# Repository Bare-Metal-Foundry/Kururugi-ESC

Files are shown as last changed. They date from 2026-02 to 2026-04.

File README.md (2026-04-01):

# ⚡ Kururugi - Electronic Speed Controller (ESC) ⚡ 

> 4/6S-ready • 64–96 kHz PWM • FOC/Six-Steps • Full bare-metal control

<p align="center">
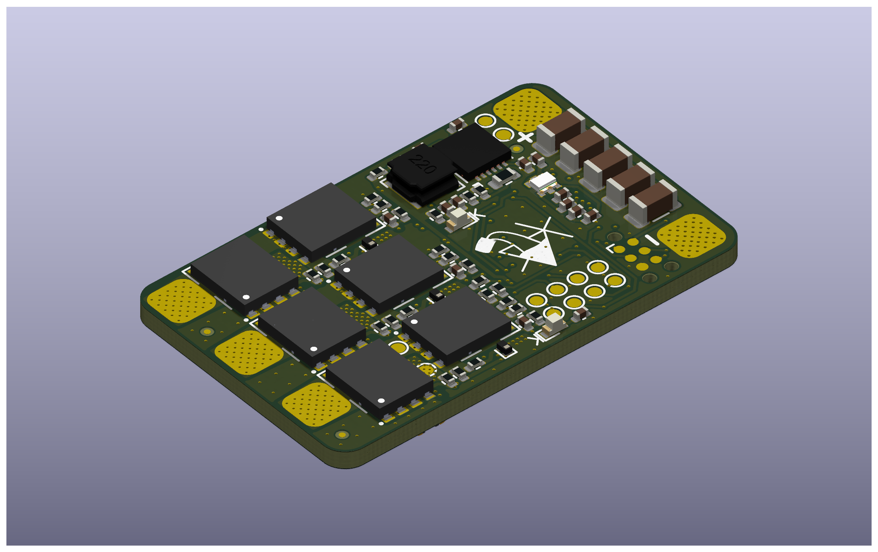
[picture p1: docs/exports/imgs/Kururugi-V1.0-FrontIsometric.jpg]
  
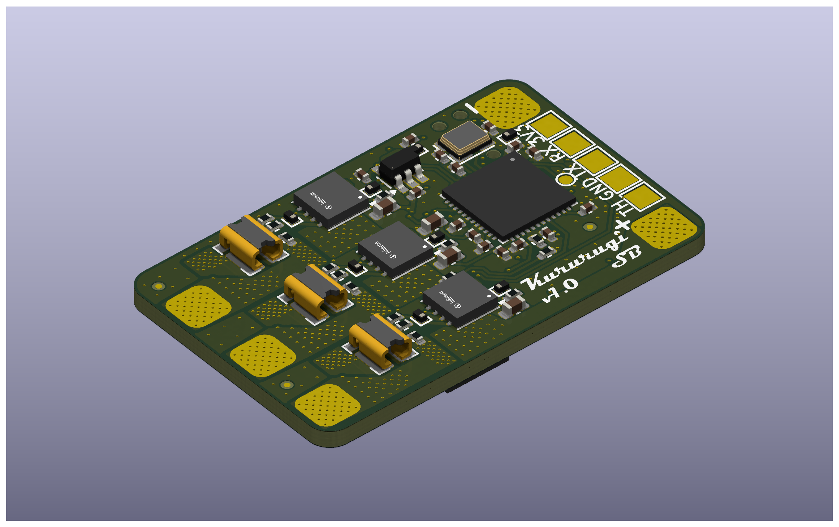
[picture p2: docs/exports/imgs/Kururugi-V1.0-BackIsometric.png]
  
  <br>
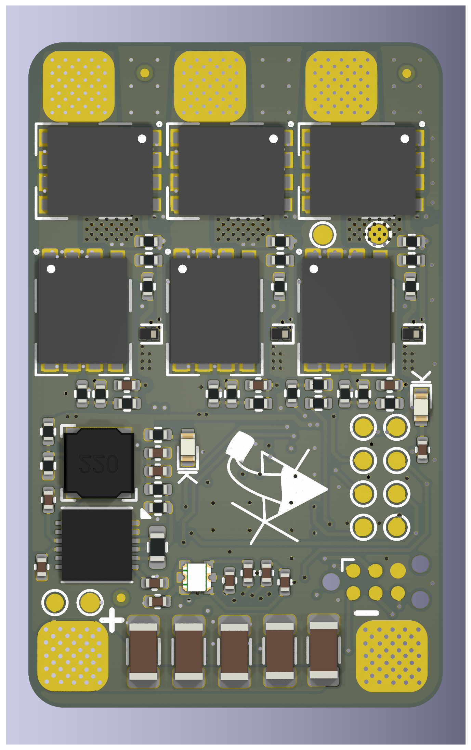
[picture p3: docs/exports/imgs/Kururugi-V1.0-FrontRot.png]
  
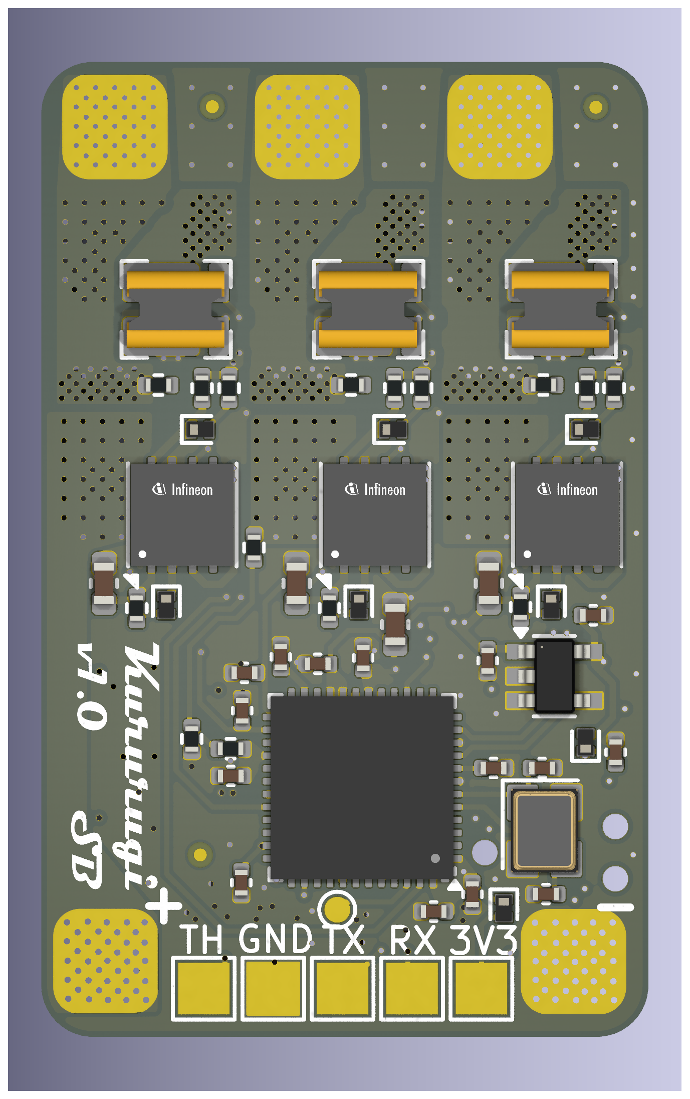
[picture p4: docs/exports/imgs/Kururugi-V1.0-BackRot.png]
  
</p>

## ⚙️ Project overview

Kururugi is a high-performance ESC designed for FPV drones, built as a platform for low-level motor control, power electronics optimization, and embedded system experimentation.

It is developed within the **Bare Metal Foundry** initiative for autonomous racing drones, alongside the Shirley Flight Controller - forming a complete, fully controlled hardware and software stack.

This README provides an overview of the project and repository structure. Detailed hardware and ESC design information is available in: 📊 [Technical Specifications](docs/hw-kururugi-specs.md)

## ❓ Why Kururugi?

Most ESCs are closed, optimized for mass production - not understanding.

Kururugi is designed to:
- Push switching frequency limits (64 kHz in v1.0, targeting 96 kHz+ in future revisions)
- Provide full transparency and control over the motor stack (no black boxes)
- Enable high-speed bare-metal control
- Serve as a platform for developing and validating Six-Step and Field-Oriented Control (FOC)
- Bring together makers and engineers to explore, experiment, and push boundaries

👉 This is an research platform, not just an ESC.

## 🚢 Navigate the repo

> ⚠️ Documentation is still a work in progress. Detailed design notes and analysis will be added progressively.

### 📂 Not to miss documents:
- 🧩 **Hardware (KiCad)**: [KiCad project](hardware/Kururugi-ESC-KiCad/)
- 📊 **Design & Sizing**: [Design notes](docs\Kururugi-ESC-sizing.xlsx)
- 📊 **Technicals specifications**: [Documentation](docs/hw-kururugi-specs.md)
- 📤 **Exports**: [Schematics, PCB renders, STEP files](docs/exports)
- 📚 **Resources**: [Datasheets & Engineering Notes](resources/datasheets)

## 💻 Run it yourself

### 📟 H/W - PCB desgin
To get started, simply clone the repository and proceed to open the project on Kicad 9.0.4. All libraries are self containts so it is no more difficult than this.
```bash
git clone https://github.com/StepaneBinon/Kururugi-ESC-Dev-Board.git
```

### 📟 H/W — PCB Manufacturing

PCB fabrication and assembly are handled through JLCPCB. The minimum order quantity is 5 boards for PCB fabrication and 2 boards for assembly. With the selected options, the total cost is 255.13 € (295.01 USD).

Production files are available in [Production files](hardware/Kururugi-ESC-KiCad/Production/).  
When placing the order, use the parameters shown in [JLCPCB Options](hardware/Kururugi-ESC-KiCad/Production/JLCPCB%20-%20Options%20to%20use.png).

> ⚠️ Ensure BOM/CPL match and components are available before ordering.
> ⚠️ This design is provided as-is; no guarantee is made regarding functionality or performance.

### 🔢 S/W - Kururugi-6Step [WORK IN PROGRESS]

### 🔢 S/W - Kururugi-FOC [WORK IN PROGRESS]

## 🚀 Roadmap

### ⚡ Hardware
1. 🧪 **V1.0 Production & Bring-up** *(Apr 2026)*: First batch with JLCPCB, full electrical validation
2. 📖 **Design Documentation** *(May 2026)*: Complete breakdown of sizing, losses, and trade-offs
3. 🔌 **Multi-ESC Test Bench** *(Jun–Jul 2026)*: Dedicated rig for synchronized testing and stress scenarios
4. 🏁 **Drone Validation (V1)** *(Jul–Aug 2026)*: High-load FPV testing on 6-inch platform
5. 🤖 **Robotics Validation (V1)** *(Jul–Aug 2026)*: Differential drive platform for control robustness
6. 📝 **Technical Paper (V1 Results)** *(Sep 2026)*: Performance, efficiency, and design insights
7. ⚡ **V2 Hardware** *(2027)*: Sensor simplification, FOC/6-step optimization, possible 4-in-1

### 🧠 Software
1. 🏗 **Bare-Metal C++ Architecture** *(Apr–May 2026)*: Deterministic design, coding standards, HAL strategy (rewrite vs minimal use)
2. ⚙️ **6-Step Control (Baseline)** *(May–Jun 2026)*: Reliable startup and fallback mode
3. 🎯 **FOC Implementation** *(Jun–Aug 2026)*: High-efficiency, high-performance control
4. 📝 **Technical Paper (Control & Results)** *(Sep 2026)*: Control strategy, tuning, and comparison

## 🤝 How to Contribute

> Alone we go faster, together we go further.

Contributions are more than welcome, at all levels:

- 🐛 **Report issues**: bugs, design flaws, or unclear documentation
- 💡 **Suggest improvements**: hardware, firmware, or architecture ideas
- 🧪 **Test & validate**: share results, measurements, or flight data
- 📖 **Improve documentation**: clarify concepts, add explanations

### 📬 Get involved

- Open an issue for discussion  
- Submit a pull request  
- Share your insights or experiments 
- Join the **Bare Metal Foundry** discord here: https://discord.gg/e7CF2AZCN 

👉 If you're working on ESCs, power electronics, or embedded control, your feedback is highly valuable.

## 🪪 Licensing

### Hardware
Hardware design (schematics, PCB, KiCad) is licensed under CERN-OHL-S v2. This project is released as open hardware.
Any modifications or derived designs must be shared under the same license.

For commercial use, collaboration, or licensing inquiries, please reach out.

## 👤 Author

This project was originally created and is actively maintained by [Stepane Binon](https://github.com/StepaneBinon).

Parts of the documentation are generated with the assistance of AI tools to streamline development.

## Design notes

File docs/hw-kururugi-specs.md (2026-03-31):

# ⚡ Kururugi ESC - Technical Specifications

> Detailed hardware architecture and performance targets

## 🧭 Overview

Kururugi is a compact, high-performance ESC designed for drones and differential-drive robotics. The design focuses on high switching frequency operation, low parasitics, and precise sensing. This version is sensorless, which limits low-speed performance. Detailed sizing is available in:
```
docs/Kururugi-ESC-sizing.xlsx
```

The design is inspired by the B-G431B-ESC1.

## 📟 Board Presentation

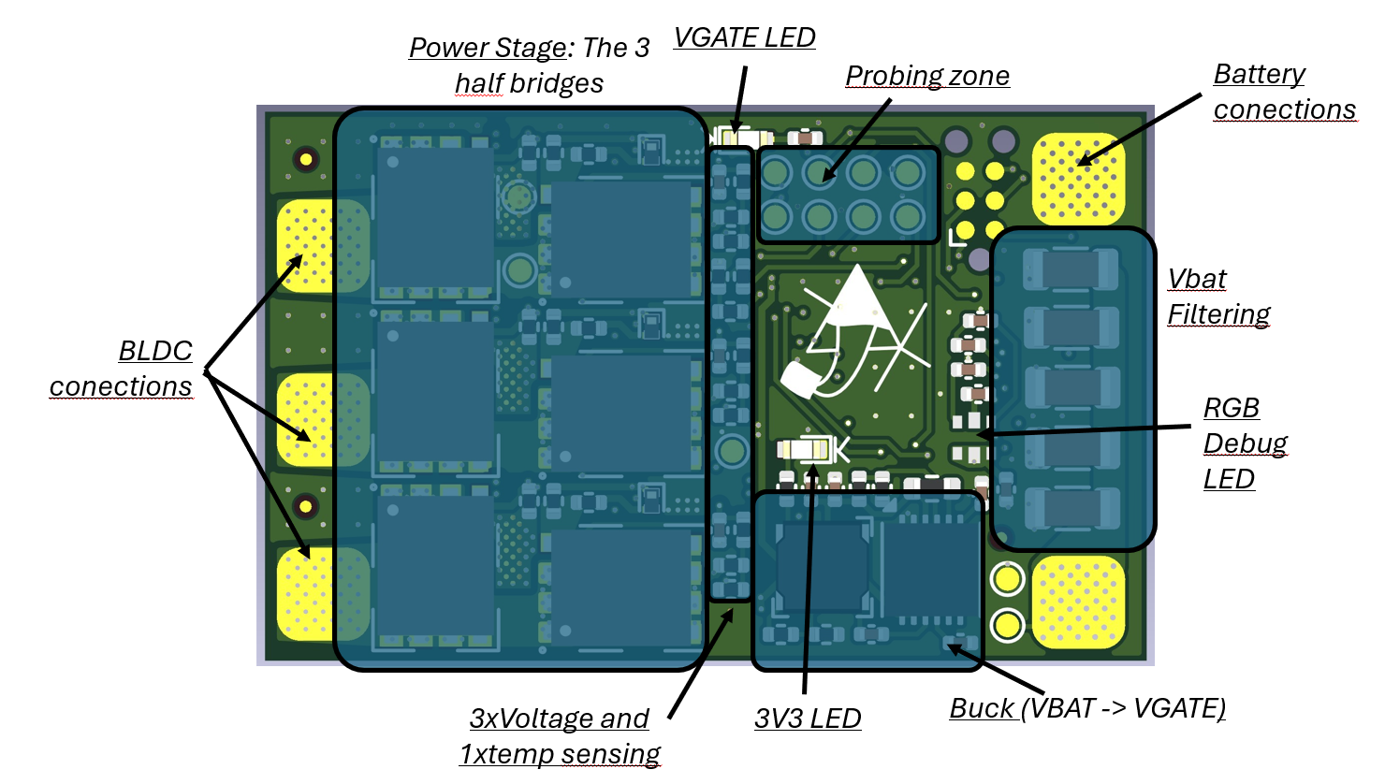
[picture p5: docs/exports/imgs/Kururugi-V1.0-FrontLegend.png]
Front

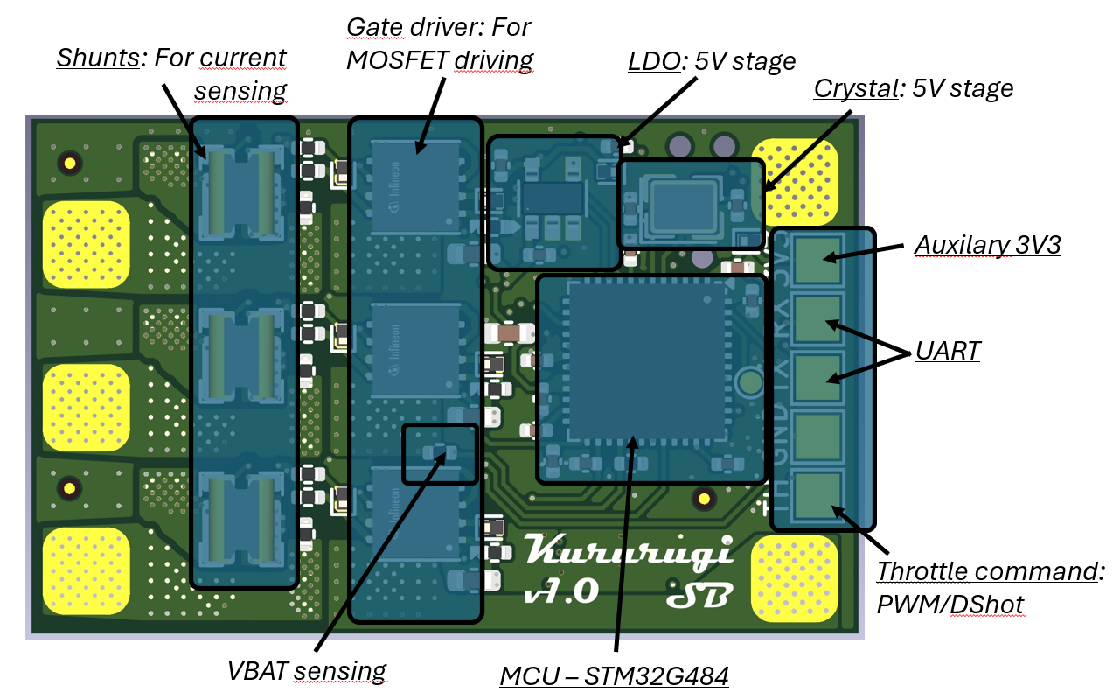
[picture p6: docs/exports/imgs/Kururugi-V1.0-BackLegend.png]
Back


## 🧱 PCB Stackup (6 Layers)

The stackup is optimized for current density, thermal performance, and EMI control.

<table>
<tr>
<td>

**Layer 1 - Power (MOSFET, BUCK)**  
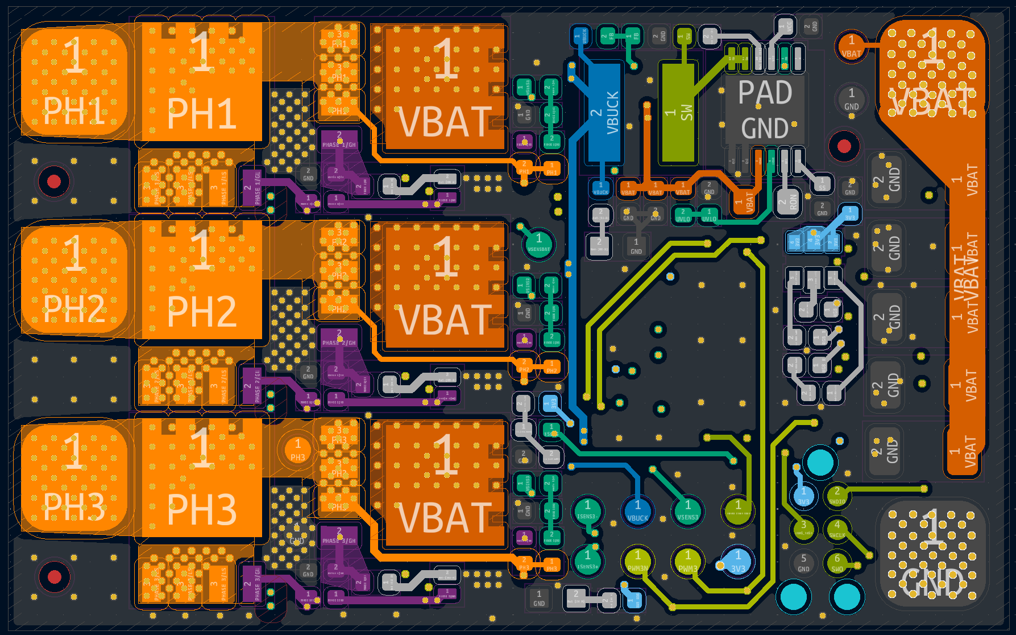
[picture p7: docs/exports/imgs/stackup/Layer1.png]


</td>
<td>

**Layer 2 - GND plane**  
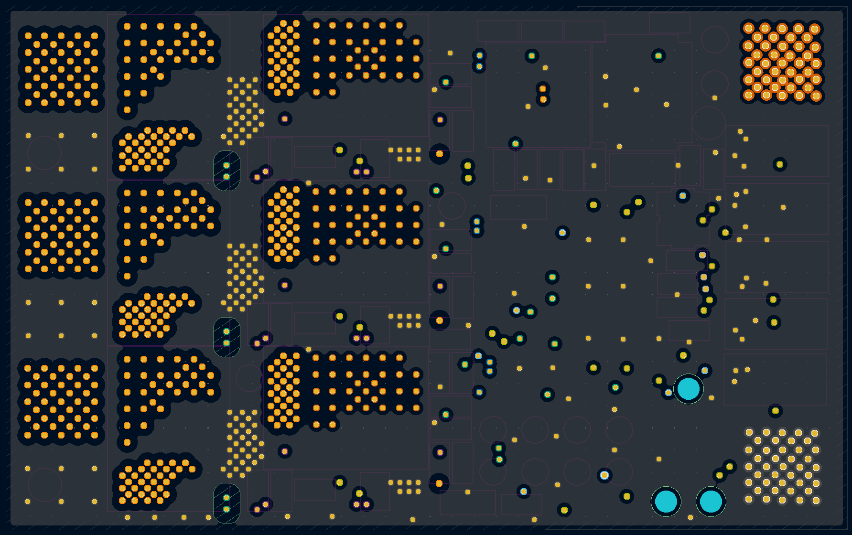
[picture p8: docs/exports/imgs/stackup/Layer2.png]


</td>
</tr>

<tr>
<td>

**Layer 3 - VBAT plane**  
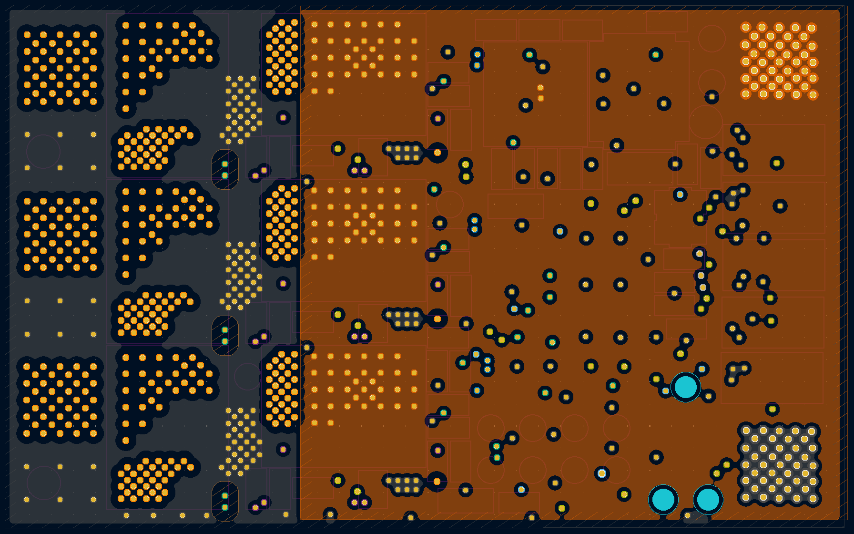
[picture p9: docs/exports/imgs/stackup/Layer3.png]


</td>
<td>

**Layer 4 - Signal routing**  
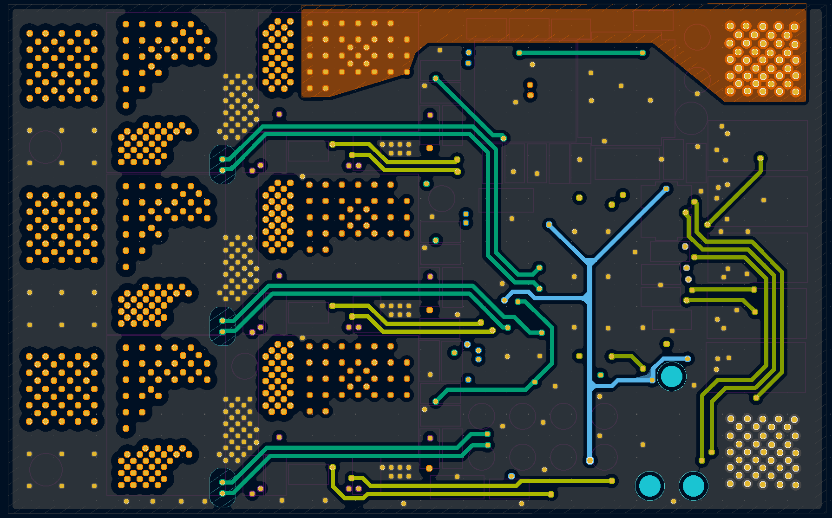
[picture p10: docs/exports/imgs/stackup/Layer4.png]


</td>
</tr>

<tr>
<td>

**Layer 5 - Clean GND reference**  
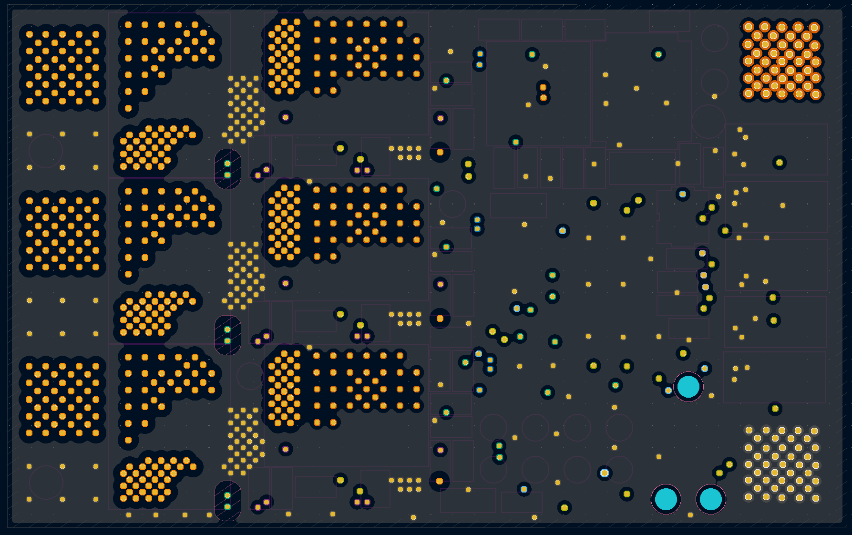
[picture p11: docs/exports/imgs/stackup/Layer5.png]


</td>
<td>

**Layer 6 - Control (MCU, shunts, LDO)**  
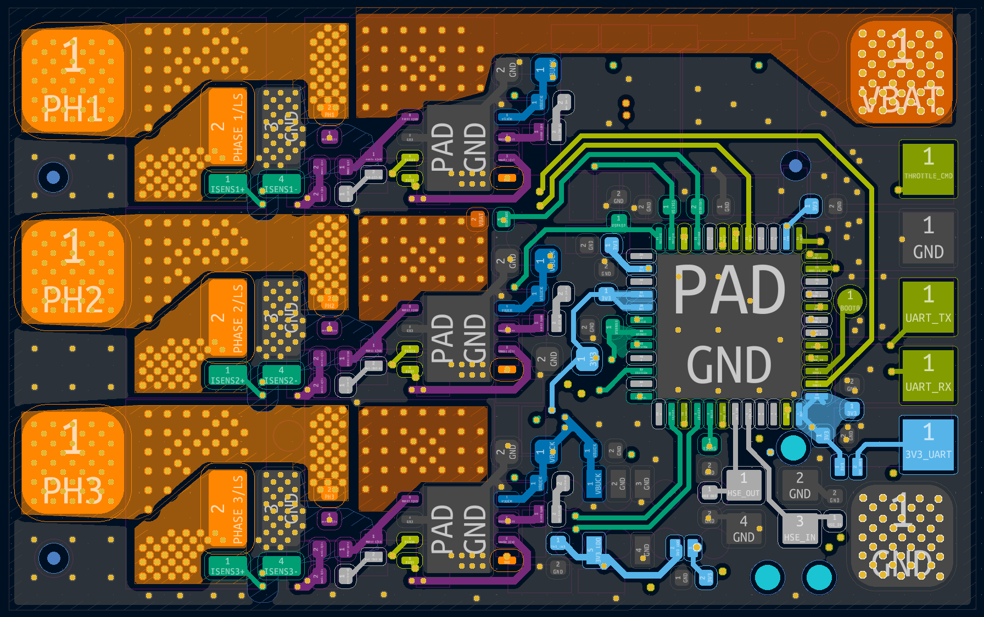
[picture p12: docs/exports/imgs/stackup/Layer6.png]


</td>
</tr>
</table>
Outer layers use 2 oz copper, and vias are filled and capped for reliable via-in-pad and thermal conduction.

## ⚙️ Subsystemps

### 1. 🧠 MCU & Sensing [[details](./hw-mcu-and-sensing.md)]

The system is built around the stm32g474 with advanced timers, ADCs, and internal op-amps.

Phase current is measured using 0.5 mΩ shunts with Kelvin routing and internal amplification. VBAT and optional phase voltages are measured through resistor dividers.

ADC sampling is optimized for speed (~2.5 cycles), with careful impedance control. A third current channel is optional due to ADC limitations.

### 2. 🔋 Power System [[details](.\hw-power-system.md)]

Three power rails are present on the board. First is VBAT, provided directly by the battery input. Then, this rails is lowered to 11.5V for the MOSFET gate driving. Finally a third rail lower the VBUCK rail to 3V3 to power the MCU and LEDs.

An extenal 3V3 pad is exposed to work with the MCU using an external power supply to work directly from an UART converter easily.

More information on the power stage can be found here: 

### 3. ⚡ Power Stage [WORK IN PROGRESS]

The design uses a three-phase half-bridge directly supplied from VBAT. Layout minimizes switching loop area and parasitic inductance while ensuring good thermal spreading.

### 4. 🚪 Gate Driving [WORK IN PROGRESS]

A high-current gate driver (~3 A / ~5 A) enables fast switching. Asymmetric gate resistors allow tuning of switching behavior and EMI.

Bootstrap capacitor sizing is critical and defined in the sizing spreadsheet.

### 5. 🌡️ Monitoring [WORK IN PROGRESS]

An NTC thermistor provides board temperature monitoring.

### 6. 📡 Communication [WORK IN PROGRESS]

A UART interface enables telemetry and future real-time monitoring tools. USB was not retained due to layout constraints.

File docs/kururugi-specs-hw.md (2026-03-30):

# ⚡ Kururugi ESC - Technical Specifications

> Detailed hardware architecture and performance targets

## 🧭 Overview

Kururugi is a compact, high-performance ESC designed for drones and differential-drive robotics. The design focuses on high switching frequency operation, low parasitics, and precise sensing.

This version is sensorless, which limits low-speed performance. Detailed sizing is available in:
```
docs/Kururugi-ESC-sizing.xlsx
```

The design is inspired by the B-G431B-ESC1.

## 📟 Board Presentation

Front
Back

## 🧱 PCB Stackup (6 Layers)

The stackup is optimized for current density, thermal performance, and EMI control.

<table>
<tr>
<td>

**Layer 1 - Power (MOSFET, BUCK)**  


</td>
<td>

**Layer 2 - GND plane**  


</td>
</tr>

<tr>
<td>

**Layer 3 - VBAT plane**  


</td>
<td>

**Layer 4 - Signal routing**  


</td>
</tr>

<tr>
<td>

**Layer 5 - Clean GND reference**  


</td>
<td>

**Layer 6 - Control (MCU, shunts, LDO)**  


</td>
</tr>
</table>
Outer layers use 2 oz copper, and vias are filled and capped for reliable via-in-pad and thermal conduction.

## ⚙️ Subsystemps

### 🔋 Power System

The ESC operates from 4S–6S LiPo input. VBAT feeds the power stage directly, while a BUCK converter generates ~11.5 V for the gate driver and an LDO provides 3.3 V for logic.

An optional external 3.3 V input allows independent MCU powering. External capacitors are recommended to reduce ringing from wiring inductance.

### ⚡ Power Stage

The design uses a three-phase half-bridge directly supplied from VBAT. Layout minimizes switching loop area and parasitic inductance while ensuring good thermal spreading.

### 🚪 Gate Driving

A high-current gate driver (~3 A / ~5 A) enables fast switching. Asymmetric gate resistors allow tuning of switching behavior and EMI.

Bootstrap capacitor sizing is critical and defined in the sizing spreadsheet.

### 🧠 MCU & Sensing

The system is built around the STM32G484 with advanced timers, ADCs, and internal op-amps.

Phase current is measured using 0.5 mΩ shunts with Kelvin routing and internal amplification. VBAT and optional phase voltages are measured through resistor dividers.

ADC sampling is optimized for speed (~2.5 cycles), with careful impedance control. A third current channel is optional due to ADC limitations.

### 🌡️ Monitoring

An NTC thermistor provides board temperature monitoring.

### 📡 Communication

A UART interface enables telemetry and future real-time monitoring tools. USB was not retained due to layout constraints.

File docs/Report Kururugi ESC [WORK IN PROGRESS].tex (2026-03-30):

\documentclass[11pt,a4paper]{article}

% =========================================================
% Packages
% =========================================================
\usepackage[a4paper,margin=25mm]{geometry}
\usepackage[T1]{fontenc}
\usepackage[utf8]{inputenc}
\usepackage{lmodern}
\usepackage{microtype}

\usepackage{amsmath, amssymb}
\usepackage{siunitx}
\usepackage{physics}
\usepackage{graphicx}
\usepackage{float}
\usepackage{subcaption}
\usepackage{booktabs}
\usepackage{tabularx}
\usepackage{array}
\usepackage{longtable}
\usepackage{multirow}
\usepackage{enumitem}
\usepackage{xcolor}
\usepackage{hyperref}
\usepackage[nameinlink]{cleveref}
\usepackage{caption}
\usepackage{listings}
\usepackage{tikz}
\usepackage{multicol}
\usepackage{siunitx}

% =========================================================
% Hyperref setup
% =========================================================
\hypersetup{
    colorlinks=true,
    linkcolor=blue,
    citecolor=blue,
    urlcolor=blue,
    pdftitle={ESC Design Report},
    pdfauthor={Your Name},
    pdfsubject={Electronic Speed Controller Design},
    pdfkeywords={ESC, power electronics, PCB, motor control, STM32}
}

% =========================================================
% siunitx setup
% =========================================================
\sisetup{
    per-mode=symbol,
    separate-uncertainty=true,
    range-phrase=--,
    range-units=single
}

% =========================================================
% Custom commands
% =========================================================
\newcommand{\projectname}{Kururugi ESC}
\newcommand{\todo}[1]{\textcolor{red}{[TODO: #1]}}
\newcommand{\figref}[1]{Fig.~\ref{#1}}
\newcommand{\tabref}[1]{Table~\ref{#1}}
\newcommand{\secref}[1]{Section~\ref{#1}}

% =========================================================
% Title
% =========================================================
\title{\textbf{\projectname}\\Design and Sizing Report}
\author{Your Name}
\date{\today}

% =========================================================
% Document
% =========================================================
\begin{document}

\maketitle
\tableofcontents
\newpage

% =========================================================
\begin{abstract}
This document presents the design, sizing, schematic capture, and PCB implementation of the \projectname.
The objective is to justify the main design choices, validate the electrical calculations, and document the final hardware implementation. To speed up the process, this document was co-written with an AI assistant.
\end{abstract}

% =========================================================
\section{Introduction}
\label{sec:introduction}

\subsection{Project context}

Electronic Speed Controllers (ESCs) are critical components in electric propulsion systems, converting battery power into controlled three-phase signals to drive brushless DC (BLDC) motors. In high-performance applications such as FPV drones, ESCs must operate under demanding conditions including high current peaks, fast switching frequencies, limited PCB area, and strong electromagnetic constraints.

This project focuses on the design of a compact and high-performance ESC tailored for aggressive drone operation. The target system requires reliable operation over a wide input voltage range (4S to 6S LiPo), high efficiency at elevated switching frequencies, and precise current sensing for advanced motor control strategies.

Beyond its functional objective, this ESC was also developed as a foundational learning project to gain hands-on experience in PCB design and low-level embedded development. It is conducted alongside the \href{https://github.com/Gui-arain/Shirley-FC-Dev-Board/tree/main/resources}{Shirley-FC development board} by \textit{Guilhem Andrieu}, forming a coherent hardware and firmware development platform.

These projects aim to serve as the technological basis for the development of fast, fully autonomous drones, and constitute the initial building blocks of the \textit{Bare Metal Foundry}, an initiative focused on mastering embedded systems from hardware to high-level software.

\subsection{Objectives}

The objective of this project is to design a compact ESC for a 6-inch FPV drone, capable of reliable operation under high electrical and dynamic stress.

The ESC must operate from 13--25.2~V, with tolerance to voltage spikes up to 45~V (battery) and 35~V (phase). It shall sustain continuous phase currents of 12.5--15~A, with peaks up to 20--25~A and transient spikes up to 50--60~A. 
High-frequency operation is targeted, up to 64~kHz (V1.0) and 96~kHz (V2), with duty cycles up to 90--95\%.

Thermally, the design must ensure safe operation through proper loss distribution, efficient PCB heat spreading, and temperature monitoring using a thermistor. Mechanically, the ESC must fit a compact layout with minimized power loops and compatibility with standard drone integration.

Functionally, it must provide accurate sensing, robust transient behavior, and support low-level firmware for high-performance motor control.

% =========================================================
\section{System Overview}
\label{sec:overview}

\subsection{Functional description}

The ESC converts DC battery power into controlled three-phase signals to drive a BLDC motor. It regulates motor speed and torque through high-frequency PWM, while monitoring current, voltage, and temperature to ensure safe and efficient operation.

The system integrates power conversion, control, sensing, and protection functions within a compact PCB suitable for FPV drone applications.

\subsection{Top-level architecture}

The ESC is organized around the following main blocks:

\noindent
\begin{minipage}[t]{0.48\textwidth}
\begin{itemize}[noitemsep, topsep=0pt]
    \item STM32G4 MCU: control, PWM, acquisition
    \item Gate driver: MOSFET control
    \item Three-phase bridge: power stage
\end{itemize}
\end{minipage}
\hfill
\begin{minipage}[t]{0.48\textwidth}
\begin{itemize}[noitemsep, topsep=0pt]
    \item Sensing: current, voltage, temperature
    \item Power supplies: regulated rails
    \item Interfaces: UART, JTAG (debug/config)
\end{itemize}
\end{minipage}

\subsection{Main design specifications}

\begin{table}[H]
    \centering
    \caption{Main design specifications}
    \begin{tabularx}{\textwidth}{>{\bfseries}l X}
        \toprule
        Parameter & Value / Description \\
        \midrule
        Input voltage & 13--25.2~V nominal (4S--6S LiPo), up to 45~V transient \\
        Continuous current & 12.5--15~A per phase \\
        Peak current & 20--25~A short duration, up to 50--60~A transient \\
        PWM frequency & Up to 64~kHz (V1.0), 96~kHz (V2) \\
        Control MCU & STM32G4 series (advanced timers, ADC, op-amps) \\
        Gate driver & Infineon 2EDL8024 \\
        MOSFETs & Low R\textsubscript{DS(on)} N-channel power MOSFETs (e.g. 60~V class) \\
        PCB dimensions & Compact ESC form factor for 6-inch drone (approx. 30~mm class) \\
        \bottomrule
    \end{tabularx}
    \label{tab:specs}
\end{table}

% =========================================================
\subsection{Design inputs and assumptions}

The first hardware revision targets a 4S--6S LiPo FPV ESC. The main design assumptions are:
\begin{itemize}[noitemsep, topsep=0pt]
    \item Input voltage from 13--25.2~V, with transients up to 45~V (battery) and 35~V (phase),
    \item Gate-driver supply around 10~V,
    \item PWM frequency up to 64~kHz (V1.0), with higher frequencies as future targets,
    \item Maximum duty cycle up to 95\%,
    \item Phase current in the 12.5--15~A range, with higher transient peaks,
    \item Conservative derating for temperature and MLCC DC bias.
\end{itemize}

A 10~V rail is generated from VBAT via a buck converter and post-regulated to 3.3~V for logic.

% =========================================================
\section{Electrical sizing}

Please refer to the sizing Excel.

% =========================================================

% =========================================================
\section{Schematic Design}
\label{sec:schematic}

\subsection{Schematic organization}

The schematic is structured into functional blocks reflecting the system architecture: power stage, gate driver, sensing, power supply, and control. This modular approach improves readability, reuse, and validation of each subsystem.

\subsection{Gate driver and power stage}

The power stage consists of a three-phase MOSFET bridge driven by the Infineon 2EDL8024 gate driver. Each half-bridge integrates bootstrap circuitry and asymmetric gate resistors to control switching speed and mitigate EMI. Particular attention is given to minimizing parasitic inductance in the switching loops and ensuring reliable high-duty-cycle operation.

\subsection{Sensing circuits}

Current sensing is implemented using low-value shunt resistors with analog amplification before ADC acquisition. Voltage sensing relies on resistive dividers with local RC filtering to ensure accurate sampling under fast switching conditions. Temperature monitoring is achieved using an NTC thermistor placed near a power MOSFET, enabling thermal supervision and derating.

\subsection{Power supply section}

The power supply is divided into two stages: a buck converter generating a 11.5~V intermediate rail from VBAT, followed by an LDO providing a clean 3.3~V rail for the MCU and analog circuits. Decoupling is applied locally at each critical node to ensure stability and reduce noise coupling. The 11.5V guarantee that, even with voltage drop from the overall circuit, the gate are driven at 10V, ensure rapid switching and thus minimizing switching losses.

\subsection{Microcontroller section}

The design uses an STM32G4 microcontroller, leveraging advanced timers for PWM generation and ADCs for synchronized measurements. Internal op-amps and comparators are used where appropriate to reduce external component count. Standard interfaces such as UART and JTAG are included for communication and debugging.

\subsection{Protection and robustness features}

The schematic integrates protection mechanisms including input voltage filtering, undervoltage lockout through the power stage, and careful layout of sensitive analog nodes. RC filtering and proper decoupling are used to mitigate switching noise. The design also considers robustness against transient events such as arming/disarming and load steps.

\subsection{Design review summary}

The schematic reflects a trade-off between performance, compactness, and robustness. Low $R_{\mathrm{DS(on)}}$ MOSFETs reduce conduction losses but increase switching constraints, requiring careful gate-drive design. Analog sensing accuracy is balanced against noise sensitivity, and the power architecture prioritizes clean supply rails over maximum efficiency. Overall, the design is consistent with the targeted operating conditions and provides a solid foundation for PCB implementation.

% =========================================================
\section{PCB Design}
\label{sec:pcb}

\subsection{Board constraints and objectives}
\todo{Size, layer count, current capability, manufacturability.}

\subsection{Stack-up definition}
\todo{Describe layers and their functions.}

\subsection{Component placement strategy}
\todo{Critical loops, thermal distribution, accessibility.}

\subsection{Power routing}
\todo{Phase paths, battery paths, copper width, polygon use, via stitching.}

\subsection{Signal routing}
\todo{Gate signals, ADC traces, sensitive nets, debug interfaces.}

\subsection{Grounding strategy}
\todo{Power ground vs quiet ground, return paths, stitching.}

\subsection{Thermal design features}
\todo{Copper areas, thermal vias, heat spreading.}

\subsection{Manufacturing and assembly considerations}
\todo{Courtyard, clearances, fiducials, test pads, DFM choices.}

\subsection{PCB review summary}
\todo{Main layout achievements and remaining limitations.}

% =========================================================
\section{Conclusion}
\label{sec:conclusion}

\subsection{Summary of the design}
\todo{Summarize the final ESC design and key results.}

\subsection{Main challenges and tradeoffs}
\todo{Discuss compromises made in sizing, schematic, and PCB.}

\subsection{Future improvements}
\todo{Possible hardware and firmware improvements.}

% =========================================================
\appendix

\section{Component List}
\label{app:bom}
\todo{Optional: add main BOM table.}

\section{Calculation Notes}
\label{app:calc}
\todo{Optional: add extra derivations not kept in main text.}

\section{Figures and Schematics}
\label{app:figures}
\todo{Optional: full-page schematic or PCB images.}

% =========================================================
\bibliographystyle{ieeetr}
% \bibliography{references}

\end{document}

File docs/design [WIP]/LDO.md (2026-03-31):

# LDO

The LDO is used to power the stm32g474. It will be powered by the 10V BUCK, hence no additionnal protection from battery spikes is required. However, the LDO input will have to handle the buck ripple and transient caused by the gate driver, that we estimed to be between 10kHz-100kHz. Moreother, the higher the Power Supply Rejection Ratio (PSRR), better the filtering of the noise. Hence, I chosed to go with the Texas Instrument TPS7B92, which, in addition to have a good PSRR, is well documented. It is rated for 300mA@3.3V, which should be enough for the MCU and some leds. However, its dropout voltage is quite hight, 1V@100mA to 3V@300mA, dissipating (10-3.3)*0.3=2W in heat. With this choice I sacrified heat for stability, which I don't think is a great choice for a digital supply. However, because my ADC sampling will be done in the MCU, this ensure, at least, a good AVcc if well used.

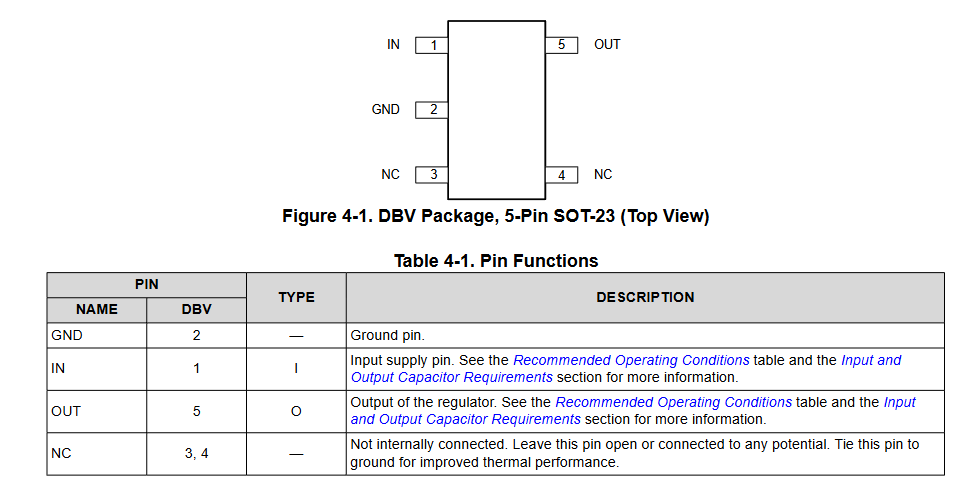
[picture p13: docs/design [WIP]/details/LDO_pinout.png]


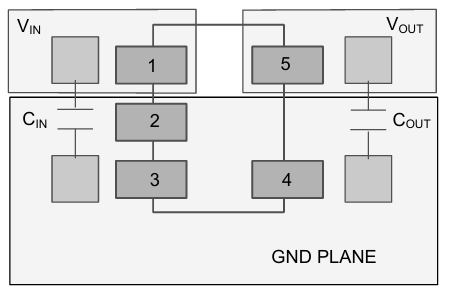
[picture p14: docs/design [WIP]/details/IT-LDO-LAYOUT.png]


## Technical Brief: Components selection.

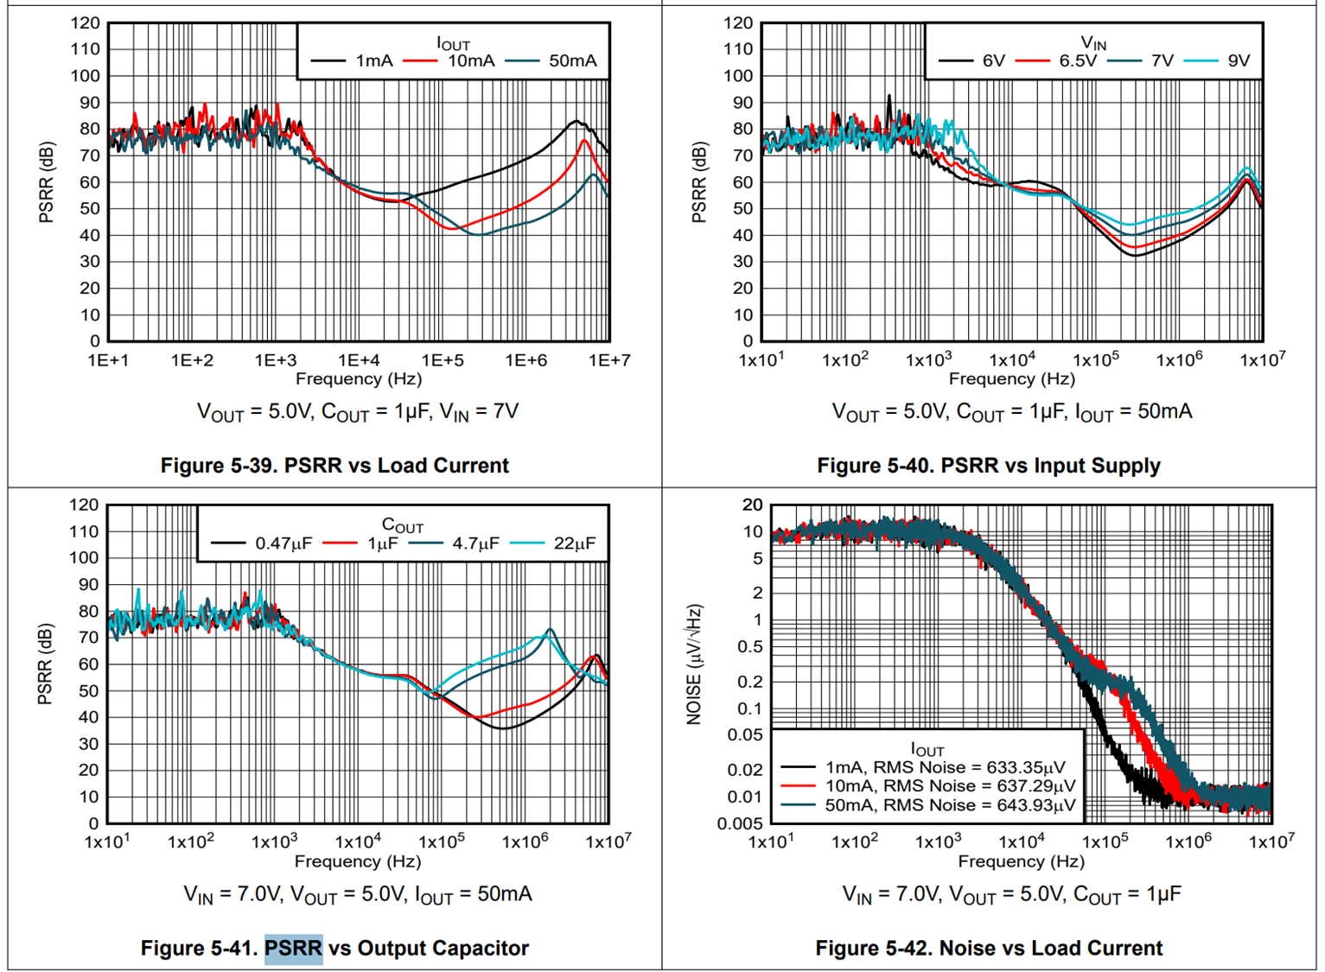
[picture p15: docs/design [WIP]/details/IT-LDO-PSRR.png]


These graphs, extracted from the database, illustrate the impact of different parameters on the PSRR. We will use a COUT=4.7µF as it balance size and performance. Finally we will rely on a CIN=1uF. The manufacturer advise to have at least 0.1µF.

The datasheet recommend to use a TVS diode in case we expect negative currents to flow in the device. However, as 10V>>3.3V, we do not expect any negative current. AS such, we wont add a TVS diode.

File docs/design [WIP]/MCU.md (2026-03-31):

# MCU: stm32g474CEU6

For the Microcontroller Unit, the stm32g474 will be used. It was chosen to use an STM MCU because we wanted to learn how to use them. We will select the smallest package as this should provide enough pins. We have two choices:

1. stm32g474CE**T**6: which comes in a LQFP48 (7x7mm) package
2. stm32g474CE**U**6: which comes in a UFQFPN48 (7x7mm) package and provide more GPIO pins, an UART port and 1 additionnal ADC channel compare to 1. It is also almost two times cheaper per unit on JLCPCB.

Thus, we will use a stm32g474CEU6 even if the soldering will be more challenging. Not that the stm32g474CEU6 does not have a dedicated VSSA pin, contrary to the STM32G474CET6, so we will need to be very careful about the layout so PWM gate signals returns and other fast varying signals returns do not cross ADC return paths.

## What is the STM32G4 familly ?

The G4 familly was specifically designed with motor control in mind an is a new adition to the STM32 catalog. The F4 is an other option we looked at, it is more general purpose. A key difference is that the G4 as stronger analogs (faster ADCs (4Msps vs 2Msps), more flexible triggering, often HRTIM, comparators, op-amps). F4 is less oriented toward power electronics.

To ensure we had some headroom for the development board we are going to use the STM32G474, one of the high tier of the familly. An other feature we looked for was the triple ADC, to reduce reading time, and the presence of an HRTIM, which are provided by the 484. An other nice to have for us is the precense of a:

- CORDIC which allows computation of sin, cos, tan, atan2, vector magnitude and polar to cartesian conversion in hardware.
- FMAC which allows FIR/IIR filtering, convolution and dot products in harware.

All these give us a lot of headroom to build the fastest ESC possible. 
[STM32G474 peripheral details](details/MCU/MCU_peripherals.md)

## Technical Briefs

Technical Briefs on design choices are available at the following location:
- [MCU pins needed for FOC control](details/MCU/periph_list.md)
- [Powering schem of the MCU](details/MCU/power_schem.md)
- [Reset pin](details/MCU/reset.md)
- [Crystal](details/MCU/crystal.md)

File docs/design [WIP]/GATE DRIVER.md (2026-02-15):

# Gate Driver

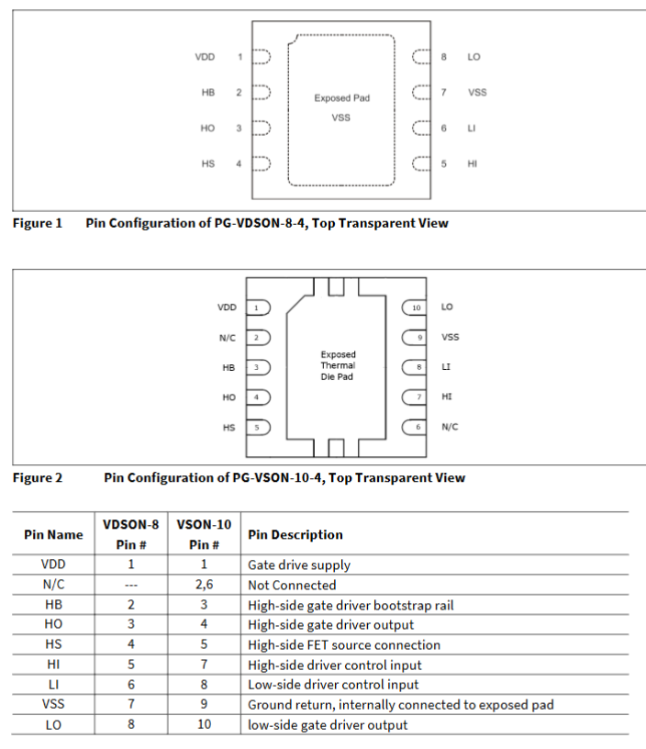
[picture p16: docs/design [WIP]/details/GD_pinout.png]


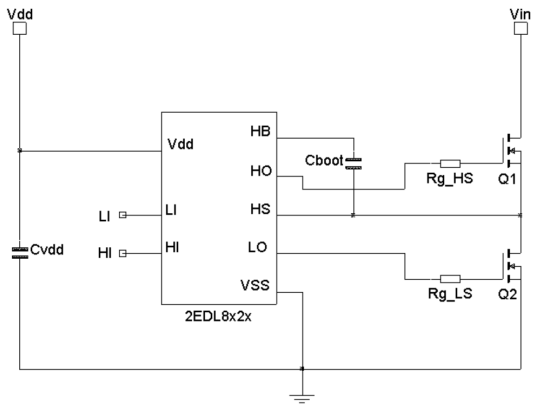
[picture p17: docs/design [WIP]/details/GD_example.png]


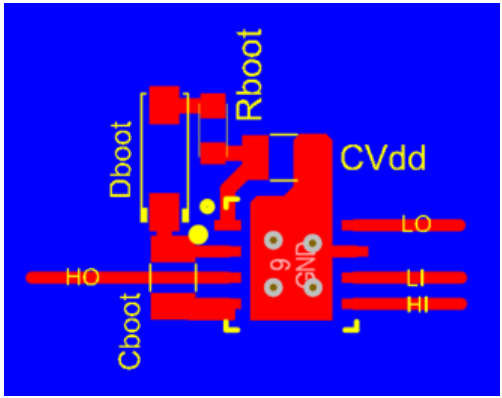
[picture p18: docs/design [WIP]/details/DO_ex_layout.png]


We will use the INFINEON 2EDL8024 as it is the one that allows the most source and sink current and the pin can be driven independently, which is great as the MCU will be resonsible for dead time. For the package, we chosed to use the VDSON-8 which is 4x4mm, slighlty lqrger, it allows better cooling and we already have a recommended footprint for it.

## Technical Brief: Selection of the Bootstrap Capacitor $C_{boot}$ and diode $D_{boot}$

An usual value in the drone context is to take Cg=1µf. Lets check it is ok with my configuration. We can use the datasheet of the INFINEON 2EDL8X2X.

a) $\Delta V_{Cboot\_max} = V_{dd} - V_F - V_{HBR} - V_{HBH} = 2.03V$

as maximum are $V_{dd} = 10V$, $V_F = 1.25V to 2.15V = 1.7V$, $V_{HBR} = 6.0V$ and $V_{HBH} = 0.27V$

b) $Q_T = Q_g + \frac{I_{HB}+(I_{HBS}+I_{pulldown})*0.95}{F_{SW}} = 238.2nC$

as maximum are $Q_g = 120nC$, $I_{HB} = 0.7mA$, $I_{HBS} = 1.25mA, I_{pulldown}=1mA$ and $F_{SW\_min} = 24kHz$, for 100% duty cycle

Both $I_{HB}$ and $I_{HBS}$ are quite high, this is a price to pays for fast propagation time and gate opening/closing.

c) $C_{boot\_min} \geq \frac{Q_T}{V_{Cboot\_max}} = 117.3nF$

Hence, we will rely on a 300nF capactiance for 50V, to ensure minimal DC biais. We expect 20% max of DC biais so 240nF which is a x2 security factor. Hence, the max tension lost during a cycle will be of dV=Qt/C=992mV and not 2.03V.

At the start of a charging cycle (high side low), due to Vf, the voltage is of Vdd-Vf-deltaV = 10-1.7-0.992=7.308V. To charge the capacitor back to its original voltage of Vdd-Vf = 8.3V. The internal diode caracteristics are mostly unknown, we only know that Vf=1.25V@100µA (end of filling) and Vf=2.15V@100mA (start of filling). We chosed the second one as reference: Rf=21.5Ohm in mean. Given the formula: R=21.5Ohm, C=240nF, Vfwanted=8V, V0=7.3V, Vdd=8.3V. Hence, 6.2µs are needed to fill the capacitor, which is not acceptable as:

- At 128kHz and 95% duty cycle $0.4\mu s$ are available to charge Cboost (ultimate goal). 
- At 96kHz and 95% duty cycle, $0.531\mu s$ are available to charge Cboost. 
- At 64kHz and 95% duty cycle, $0.781\mu s$ are available to charge Cboost.
- At 48kHz and 95% duty cycle, $1.042\mu s$ are available to charge Cboost.
- At 24kHz and 95% duty cycle, $2.083\mu s$ are available to charge Cboost.

Thus, 2 methods can be employed:
1. Add an additionnal diode
2. Raise Vdd

Let first add an additional diode and a 5R resistor. We selected the RB161QS-40 which as a forward voltage of 0.38V (+0.5V from resistor) at 100mA and a reverse current of 40µA. Bringing $\Delta V_{Cboot\_max} = 2.85V$, $Q_T \approx 238.2nC$ and $C_{boot\_min} \geq = 83.6nF$.

To keep the x2 security factor, we select a 200nF (DC biais 150nF) capacitance for Cboot, so $\Delta V_{Cboot\_max} = 1.59V$ during a cycle. We chosed the second one as reference: Rf=21.5Ohm in mean. Given the formula: R=4.06Ohm, C=150nF, Vfwanted=8.1V, V0=8.03V, Vdd=9.62V. Hence, 0.2µs are needed to fill the capacitor. This time, it is possible to work at an high duty without major compromise on Vboot!

Computation are sum up here, we can see that using 11V from start add a lot of benefits! The downside to work at lower voltage is that Rdson increase on long duration.

We can, using the formula given, compute the consumption at 128

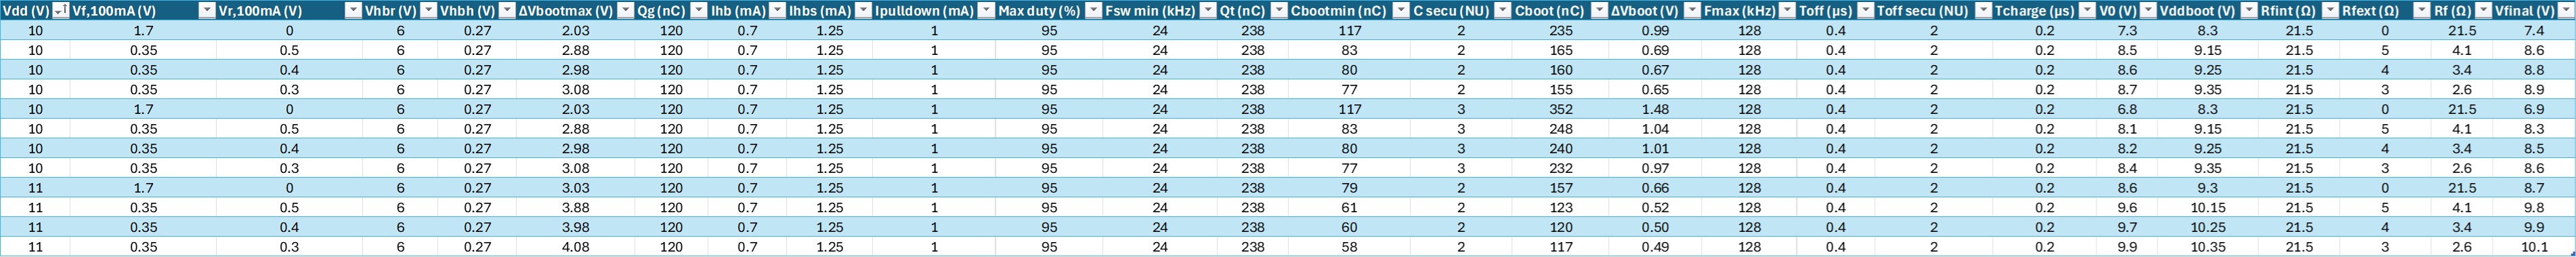
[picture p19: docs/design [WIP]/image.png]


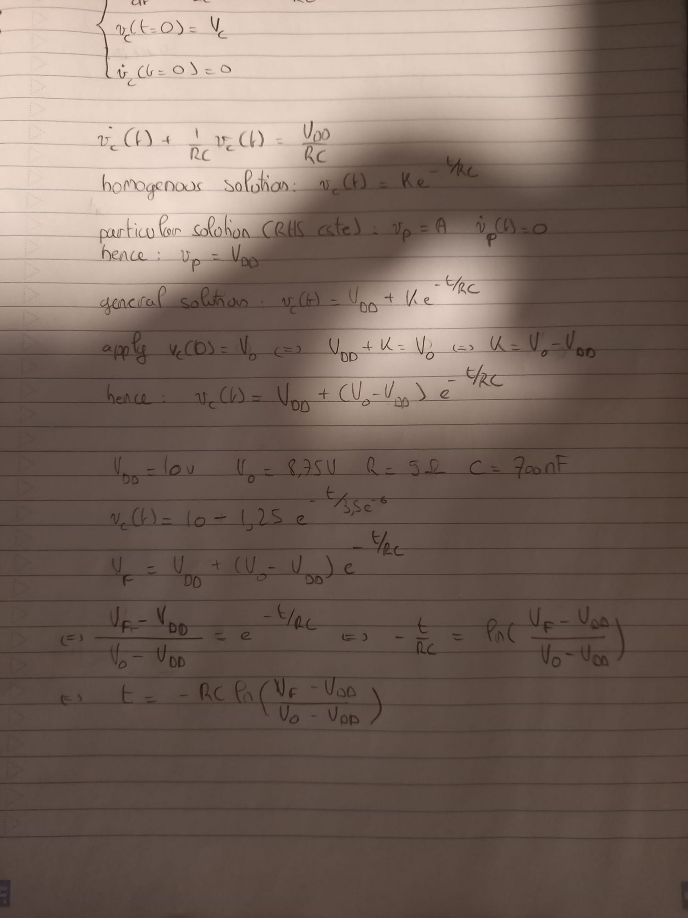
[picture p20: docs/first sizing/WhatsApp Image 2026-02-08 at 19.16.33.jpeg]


## Technical Brief: Selection of the Gate Resistor $R_{G}$

We can change these capacitance after installation so we will first select one that allows low EMI to ensure reliability. 

It is important to keep the gate turn-off resistance $R_{G,\text{off}}$ sufficiently low to ensure immunity against displacement currents generated by high $\mathrm{d}v/\mathrm{d}t$ during switching off events. Rapid voltage transitions at the drain induce a displacement current through the gate–drain (Miller) capacitance $C_{GD}$ that may re-trigger the mosfet.

If $R_{G,\text{off}}$ is too large, this current cannot be evacuated quickly and instead charges the gate capacitance $C_{GS}$, causing the gate voltage to rise. In extreme cases, $V_{GS}$ may exceed the threshold voltage, resulting in unintended self turn-on of the MOSFET, increased switching losses, or shoot-through in a half-bridge configuration.  

Using a low $R_{G,\text{off}}$ provides a low-impedance path to rapidly sink the Miller-induced current and clamp the gate voltage close to the source potential during turn-off. In addition, a dedicated gate-to-source pull-down resistor (typically around 10 kΩ) ensures a defined OFF state when the driver is high-impedance (startup, reset, or fault conditions) and prevents long-term charge accumulation on the gate due to leakage or capacitive coupling.

We will take $R_{G,on} = 10\Omega$ and $R_{G,off} = 5\Omega => 10\Omega$ as resistances are parallel. We will use the same diode as for the bootstrap capacitor. 

This will cap the source current at 1A and the sink current at 2A, which will allow us to make the first steps before scaling up to bigger values (4A source and 5/6A sink max).

We estimate the gate-drive dissipation starting from the MOSFET gate charge.

Given a total gate charge \(Q_g = 120\,\text{nC}\) at a gate voltage of \(V_{GS} = 10\,\text{V}\), the gate can be approximated by an equivalent capacitance:
$C \approx \frac{Q_g}{V_{GS}} = \frac{120\,\text{nC}}{10\,\text{V}} = 12\,\text{nF}$

The energy dissipated in the resistive gate-drive path during a single charging event (turn-on) is:
$E_{\text{on}} = \tfrac{1}{2} C V_{GS}^2
= \tfrac{1}{2} \cdot 12\,\text{nF} \cdot 10^2
= 600\,\text{nJ}$

During turn-off, the energy stored in the gate capacitance is discharged through the gate-drive path and dissipated as heat:
$E_{\text{off}} = \tfrac{1}{2} C V_{GS}^2 = 600\,\text{nJ}$

Therefore, the total energy dissipated per complete switching cycle (turn-on + turn-off) for one MOSFET is:
$E_{\text{cycle}} = E_{\text{on}} + E_{\text{off}} = 1.2\,\mu\text{J}$

At a switching frequency of \(f_{sw} = 128\,\text{kHz}\), the average gate-drive power per MOSFET is:
$P_{\text{gate}} = E_{\text{cycle}} \cdot f_{sw}
= 1.2\,\mu\text{J} \cdot 128\,\text{kHz}
\approx 154\,\text{mW}$

Since two MOSFETs are driven simultaneously in the half-bridge (neglecting additional commutations due to phase changes), the total gate-drive dissipation is approximately:
$P_{\text{HB}} \approx 2 \cdot 154\,\text{mW} \approx 310\,\text{mW}$

This level of dissipation is acceptable given an idle board thermal budget of approximately 1–2 W. Other sources of heat (MOSFET conduction losses, switching losses in the power stage, driver losses, etc.) must of course be considered separately.

In practice, operation at 128 kHz is not targeted for the first hardware revision, both because the gate charge cannot be transferred fast enough with the chosen gate resistance and to preserve additional thermal margin. A maximum switching frequency of 64 kHz is therefore planned for V1, providing significant headroom on gate-drive dissipation.

At 128kHz, 95%D, we have Qton=142.2nC and Qtoff=125nC, hence at 10V, we need to dissipate 335mW in thermal (i think there is a error, tthis is for 2 fets?). The internal resistance of the IC are:
- HS/LS pull up: 1R
- HS pull down: 0.5R
- LS pull down: 0.35R

So $P_{R_g} = \frac{R_g}{R_g+R_{out}}*P_{g}$, the mean of Rout on a cycle is 2.85R, so $P_{R_g} = 261mW$. The IC dissipate 74mW.

Also, on the pull down, the second Rg also dissipate so $P_{R_g1} = 261/2 * (1 + 0.5) = 196mW$ and $P_{R_g1} = 261/2 * (1 + 0.5) = 65mW$

## Technical Brief: Selection of the Bypass Capacitor $C_{V_{dd}}$

Common rules is to have $C_{Vdd} \geq 10 \sim 20 * C_{boot}$. Hence, for safety, we will take 15µF in a 3216m/3225m package.

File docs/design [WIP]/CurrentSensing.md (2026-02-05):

# Current sensing

First of all, we cannot sample with the adcs of the smt32g484 directly as the voltage drop for a reasonable amount of dissipated power is too low. We also cannot go a lot much lower 100µOhm resistor as really robust analogic will be needed (none are available on digikey).

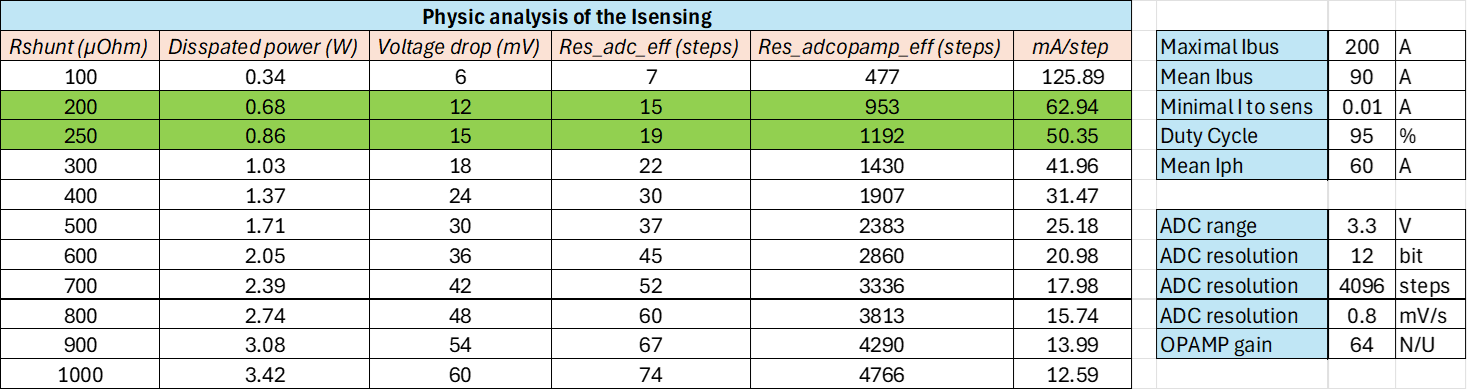
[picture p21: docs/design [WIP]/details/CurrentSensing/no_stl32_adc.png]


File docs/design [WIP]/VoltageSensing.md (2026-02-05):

# Voltage Sensing

We must protect the ADC (3.3V) pin from surge that can be of 45V. So the tension divider:

Vadc = r1/(r1+r2) Vph => r1(Vadc - Vph) + r2Vadc = 0 => r1/r2 = Vadc/(Vph - Vadc) = 0.079

For the sensing of voltage, we face multiples issues:

1. 
As the ESC surface is really small, it is important to have a divider bridge with the largest resistance possible as less heat will be produced. The resistance of a divider bridge, when the current is not flowing, is Rtot = R1+R2.

2. 
In the same time, if Rtot is to strong, then the current passing trought R1&R2 is low. This is an issue as the charging speed of the ADC capacitor is dependent of the current flowing in. This can be computed using the thevenin equivalent with respect to the adc pin:

Vth = r1/(r1+r2)

Rth = r1r2/(r1+r2)

And as Ino = Vth/Rth, we can expect Rth to have an important impact on the current that can flow in the ADC capacitance.

This is demonstrated bellow, where we can observe that with no ADC pin external capacitance, we cannot hope for great precision and great termal control. To change this, we could use a buffer but this would add some footprint and otherall complexity. A easier option is to add a adc pin external capacitance, as we have margin on the filtering frequency, this won't have a drastic impact on performances, this is presented on the second image with 470pF. The drastic gain on S*RC is due to the resistance being set to 100 ohm on the ext capa to adc capa. 

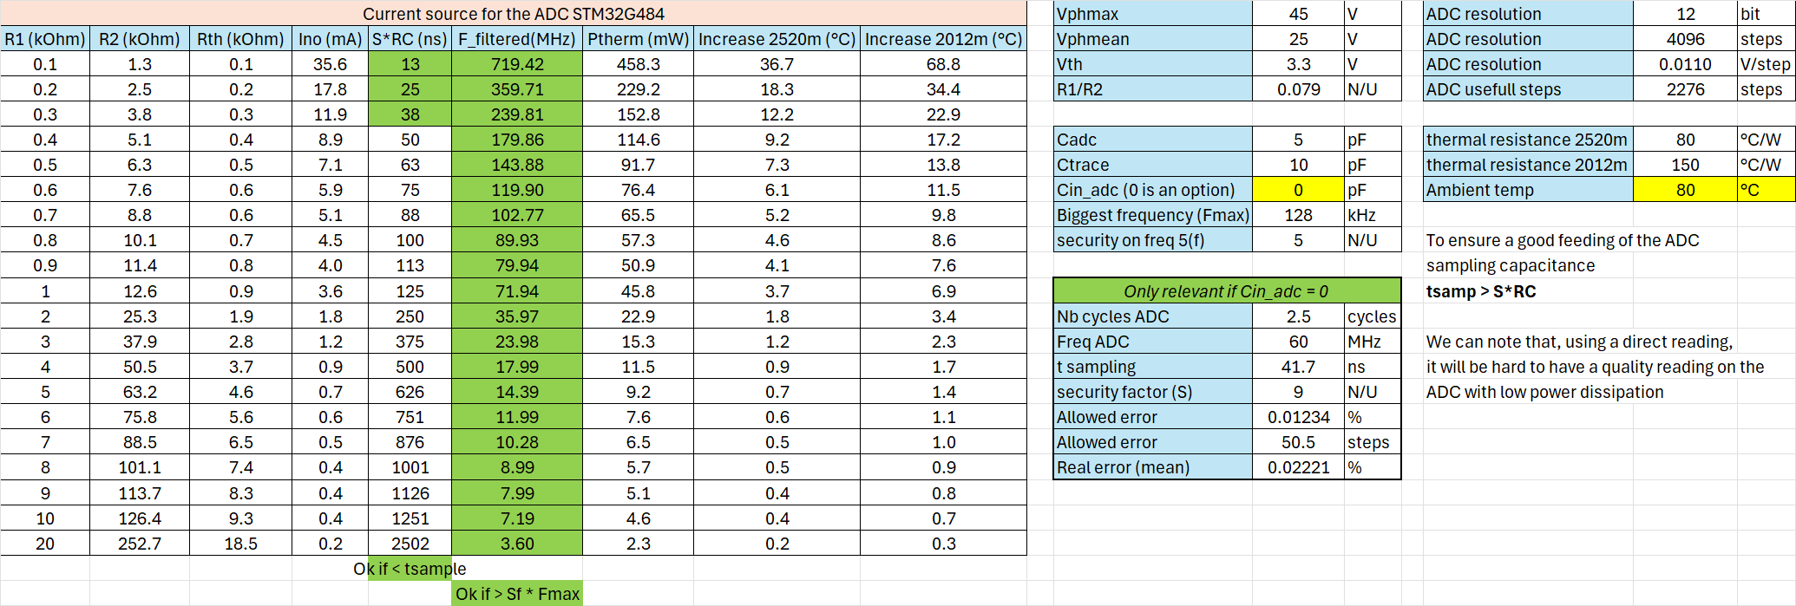
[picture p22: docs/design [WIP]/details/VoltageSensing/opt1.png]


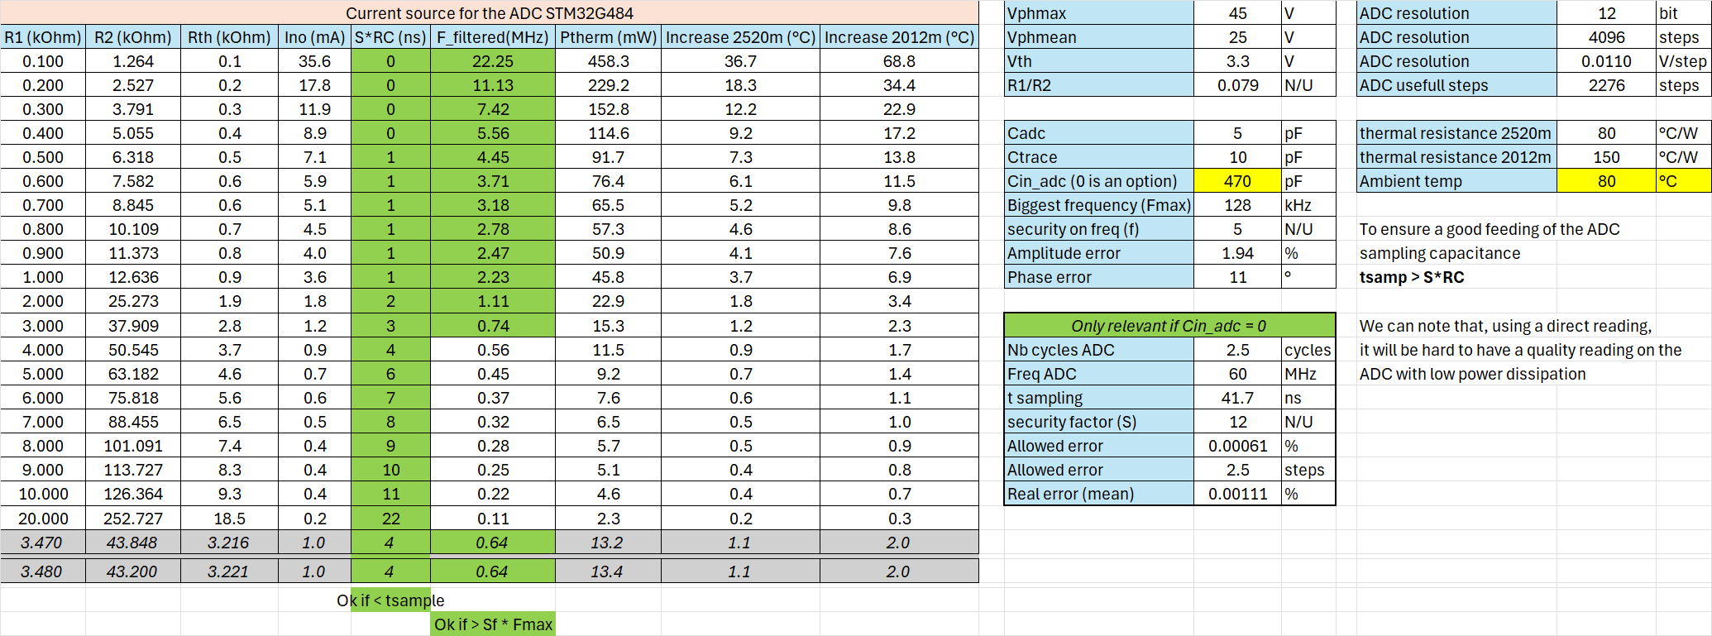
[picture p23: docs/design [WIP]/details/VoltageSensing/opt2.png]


We also have to consider that the added capacitor itself is slow to fill up. He will fill during the noisy blanking phase so it has to be fast to settle (<480ns). This is presented in the next figure. As it has to settle pretty fast, we decided to double the security factor (or charge factor) from 12Tau to 24Tau

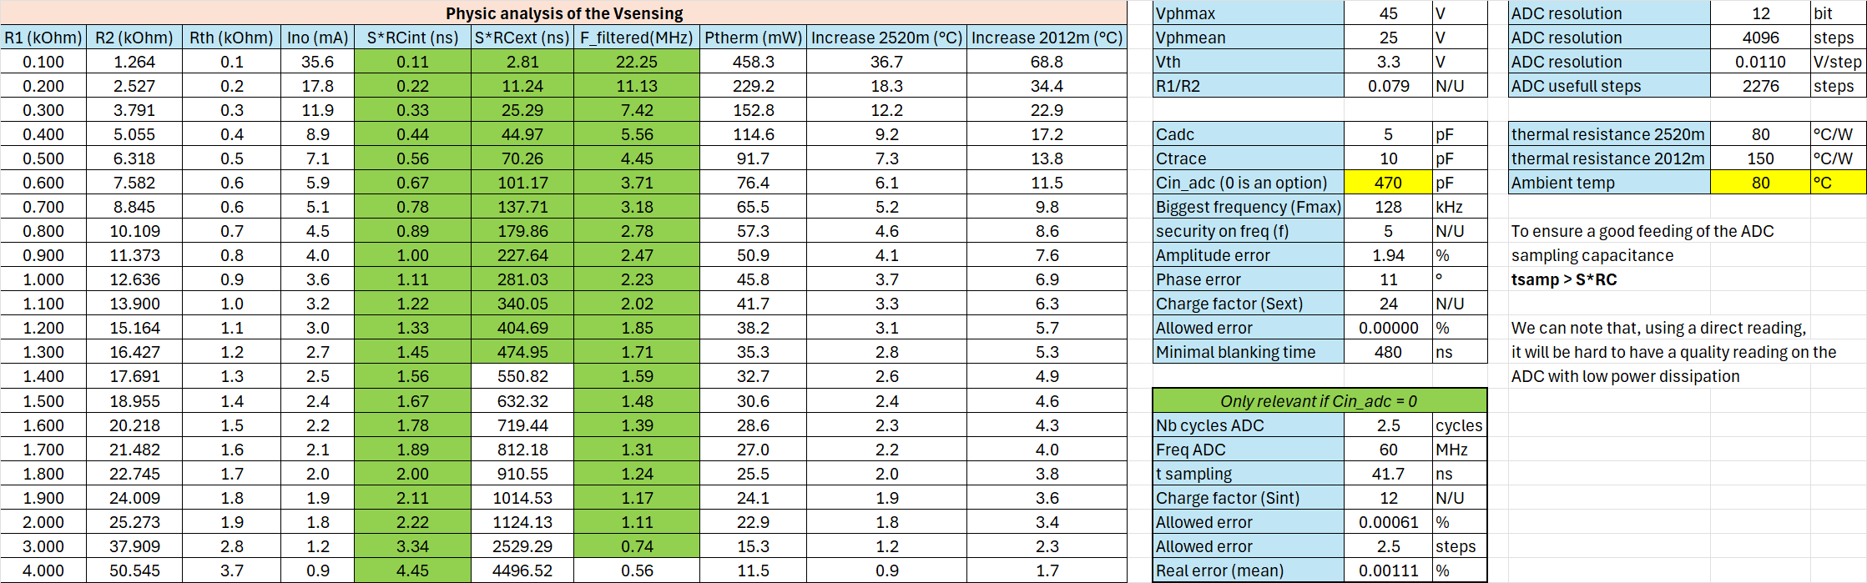
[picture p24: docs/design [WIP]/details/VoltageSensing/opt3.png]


We can expect the whole ESC to be able to dissipate 1.5W still and 3W in forced air

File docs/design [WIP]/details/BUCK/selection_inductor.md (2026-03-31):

# Technical Brief: Selection of the induction - L

The datasheet specified that the saturation current of the inductance must be higher than 2.48A, but this would result in a physically large inductance SMD part, which we cannot afford as compactness is important. Hence, we will estimate an approximation of the all time max current output of the BUCK.

We estemeed the max current to be 590mA according the following value:
1. The LDO (STM32G474 & other): 300mA
2. The 2xGD (2EDL8X2X): 61x2 = 120mA (with a x2 security coeficient)
3. Margin (24%): 100mA

Taking some margin, we will size the buck for $I_{O,max}>522mA$. The highest operating point for such a load, considering sag, is set at 26V. Fsw = 833kHz. Following next equation, it appears that a std 22µH inductance will allows a max current ripple of ~65%.

$L_{\min} = \frac{V_O \times \left( V_{IN,\max} - V_O \right)}{V_{IN,\max} \times F_{SW}\times  I_{O,\max}\times  65\%} = 21.8\mu H$. We will use a 22µH.

Furthermore, current delta pic to pic is 

$\Delta I_L
= \frac{V_O\left(V_{IN}-V_O\right)}{V_{IN}\,L\,f_{SW}} = 336\text{mA}_{pp}$

So Ioutmax = 758mA and Ioutmin = 422mA.

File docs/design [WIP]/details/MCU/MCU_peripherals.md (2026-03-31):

# STM32G474 – Peripheral Overview (concise)

## Core & System
- **Cortex-M4F CPU (170 MHz)**  
  MCU core with FPU and DSP instructions for real-time control.
- **NVIC / SysTick**  
  Interrupt controller and system timer.
- **CRC**  
  Hardware CRC calculation.
- **DBG / SWD**  
  Debug and trace interface.

## Memories
- **Flash memory**  
  On-chip program storage.
- **SRAM**  
  Data and stack memory.
- **ART accelerator**  
  Zero-wait-state Flash access at high clock.

## Analog peripherals
- **ADC (3× 12-bit, up to 4 Msps each)**  
  Fast, hardware-triggerable ADCs with oversampling and injected channels.
- **DAC (2× 12-bit, 4 channels total)**  
  Waveform generation, references, thresholds.
- **Comparators (6×)**  
  Fast analog comparators with internal routing to timers/ADC (faults, ZC).
- **Operational amplifiers (4×)**  
  Configurable PGA or follower for current sensing and signal conditioning.
- **Internal voltage reference (VREFBUF)**  
  Stable reference for ADC/DAC/comparators.
- **Temperature sensor / Vbat monitor**  
  Internal monitoring sources.

## Advanced math accelerators
- **CORDIC**  
  Hardware sin/cos, atan2, magnitude, vector rotation.
- **FMAC**  
  Hardware FIR/IIR filters, dot products, convolution.

## Timers
- **HRTIM**  
  High-resolution timer (~184 ps) for SMPS, advanced PWM, dead-time, faults.
- **Advanced timers (TIM1, TIM8)**  
  Complementary PWM, dead-time, break inputs (motor control).
- **General-purpose timers (TIM2–TIM7, etc.)**  
  Time bases, input capture, output compare.
- **Low-power timers (LPTIM)**  
  Low-energy timing and pulse counting.
- **RTC**  
  Calendar and timekeeping.

## Communication interfaces
- **USART / UART (multiple)**  
  Serial communication.
- **SPI / I²S**  
  High-speed synchronous serial.
- **I²C**  
  Standard and fast-mode serial bus.
- **FDCAN**  
  CAN-FD controller for robust field networks.
- **USB FS (device)**  
  Full-speed USB device interface.
- **IRDA / LIN / SmartCard support**  
  Via USART modes.

## Data movement & glue
- **DMA (with DMAMUX)**  
  High-throughput peripheral↔memory transfers with flexible routing.
- **DMAMUX request generator**  
  Timer/event-driven DMA triggers.
- **Event system (internal routing)**  
  Peripheral-to-peripheral connections without CPU.

## Security & safety
- **Independent watchdog (IWDG)**  
  Hardware fail-safe reset.
- **Window watchdog (WWDG)**  
  Software supervision.
- **Brown-out reset (BOR)**  
  Supply voltage monitoring.
- **Memory protection unit (MPU)**  
  Region-based memory access control.

## Clock & power
- **RCC**  
  Clock generation and distribution.
- **PLL / HSI / HSE / LSI / LSE**  
  Flexible clock sources.
- **Low-power modes (Sleep/Stop/Standby)**  
  Energy management.

## GPIO & external
- **GPIO with EXTI**  
  Digital I/O and external interrupts.
- **AF matrix**  
  Flexible pin multiplexing.

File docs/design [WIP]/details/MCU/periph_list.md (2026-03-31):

# STM32G474 — GPIO / Peripherals for Sensorless FOC ESC

## Inputs
- Phase currents **Ia, Ib, Ic** → **3× PGA OPAMP ( → 3× ADC internally)**
- DC bus voltage **Vbus** → **1× PGA OPAMP ( → 1× ADC internally)**
- Board / FET temperature (NTC) → **1× PGA OPAMP ( → 1× ADC internally)**
- Throttle / command input:  → **1× Timer input (DMA)**
    - **DSHOT**
    - **PWM / PPM (alternative)**
- Reset button → **1× GPIO**

## Outputs
- 3-phase inverter drive → **TIM1 or HRTIM: 3 PWM + 3 complementary outputs + deadtime**
- Buzzer → **1× GPIO**
- Status RGB LEDs → **3× GPIO** 

## Bidirectional / Debug / Communication

- **SWD (J-Link)**
    - **SWDIO**: Bidirectional data line (debug + flash) → **PA13**
    - **SWCLK**: Debug clock → **PA14**  
    - **NRST**: Allows full device reset, recovery from bad clock / low-power lockups → **NRST pin**
    - **SWO (ITM trace)**: Real-time printf / event tracing (single-wire trace) → **PB3**  
- **USB FS (CDC / DFU)**
    - **USB_DM**: Differential data line (D−) → **PA11**  
    - **USB_DP**: Differential data line (D+) → **PA12** 
    - **VBUS sense**: Used to detect cable presence → **1x GPIO**

## Grand Total

- **ADC pins**: 5  
- **PWM pins**: 6  
- **Timer input pins**: 1  
- **USB pins**: 2  
- **GPIO pins**: 6  
- **Debug pins**: 4  

➡️ **Total MCU pins used: 24**

The STM32G474CEU6 will provide 48 pins, which should be largely enough.

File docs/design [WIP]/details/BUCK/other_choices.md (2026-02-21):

# Other choices

Following are listed some other engineering choices for the buck converter layout.

## Technical Brief: Output capacitor $C_{out}$

We have $\Delta I_{L,\max} = 397mA$ and we want 10mV of variation maximal. Hence, $C_{OUT} = \frac{\Delta I_{L,\max}}{8 \times f_{SW} \times \Delta V_{O,\text{ripple}}} = 5.5\mu F$. We will take $C_{OUT} = 1\times10 = 20\mu F$. We chosed to use 2 capacitance to reduce ESR in X7R with 2012m format with a voltage range of 25V to limit the impact of DC biais (6 to 8µF expected).

## Technical Brief: Forced PWM (FPWM)

If FPWM is put to low, then the efficiency is increased. The low side mostfet behave as a diode and some commutation steps can be skip if low cuurent is required. However, this create some noise and less predictable behavior overall as steps can be skipped. Thus we will force CCM by putting FPWM to high.

## Technical Brief: Selection of the Feedback Resitors

$V_{OUT} = \frac{V_{REF} \times (R_{FB1} + R_{FB2})}{R_{FB1}}$, specified in the datasheet.

Where $V_{REF} = 2V$. We want $V_{OUT} = 10V$ so $\frac{R_{FB2}}{R_{FB1}} = 4$. We should try to keep the sum (lost power), in the $10k\Omega \text{ to } 100k\Omega$ order. We will use 10kR and 39.2kR, so $V_{REF} = 2.041V$

## Technical Brief: Selection of the Current Limit Timer $C_{VCC}$

It is recommended to have $C_{VCC} = 1\mu F$, good quality X7R.

## Technical Brief: Selection of the Soft Start Capactor $C_{SS}$

Soft start is important to limit current flow at ESC start as all capactior will require to be chatge simultaneously. If well control, it could even be used to reduce the resistance of the external boostrap diode resistance of the gate drivers so we can charge it faster during normal operation.

$C_{ss}$ must be greater than 1nF. For VersionV1.0, having a long soft start seems very relevant to avoid bug. In general, having a long start for ESC does not have an major impact.

$C_{SS} = \frac{I_{SS} \times T_{\text{startup}}}{V_{SS}}$

With $V_{SS} = 2V$, $I_{SS} = 10\mu A$ and $C_{SS}=1\mu F$, we have $T_{\text{startup}} = 200ms$.

## Technical Brief: Selection of the Current Limit Timer $C_{BST}$

It is recommended to have $C_{BST} = 10nF$, with a good quality X7R. It is fed by $C_{VCC}$ during off times.

## Technical Brief: Under voltage lockout - RUV1/RUV2

We decided to aim for 12.0V minimum Vbat so $V_{IN,\text{rise}}=12V$. We also need an important hysteresis as the battery will have a lot of sag, hence $\Delta V_{IN}=4V$ and, it is given $I_{HYS}=20µA$. This enforces:

$R_{UV2} = \frac{\Delta V_{IN}}{I_{HYS}} = 200\,\text{k}\Omega$. 

We want $V_{IN,\text{rise}} = 14V$ and have $V_{UVLO,\text{TH}} = 1.24V$. Hence:

$R_{UV1} = \frac{R_{UV2}}{\left(\dfrac{V_{IN,\text{rise}}}{V_{UVLO,\text{TH}}} - 1\right)} = 23k\Omega$

We will take $R_{UV1}=22\text{k}\Omega$ and $R_{UV2}=200\text{k}\Omega$



## Technical Brief: Input cqpqcitor CIN

Maximum allowed ripple is around 0.25V. D=10/24=0.4.

$C_{IN} = \frac{I_{O,\max} \cdot D \cdot (1 - D)}{\Delta V_{IN,\text{ripple}} \cdot F_{SW}} = 1\mu F$

## Technical Brief: Selection of the Collector Voltage $V_{CC}$

As the $V_{out}$ voltage is 10V, $V_{cc}$ could be powered using $V_{out}$ to gain efficiency and limit termal losses inside the chip (with the LM5160A chip). It is not implemented as it adds layout complexity for a gain we deemed minimal.

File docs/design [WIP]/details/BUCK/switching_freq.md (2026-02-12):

# Technical Brief: Switching Frequency - $R_{on}$

### Check minimal off time

First, we need to ensure that the buck can work for the minimum V_in of a 4S fully empty LIPO which is 4x3=12V, t_off typical is 170ns.

$F_{SW, \max(@V_{IN, \min})} = \frac{V_{IN,\min} - V_{OUT}}{V_{IN,\min} \cdot T_{OFF,\min}}$

1. For $V_{IN, \min} = 10.5V, F_{SW} = 280kHz$
2. For $V_{IN, \min} = 11.0V, F_{SW} = 535kHz$
3. For $V_{IN, \min} = 11.5V, F_{SW} = 768kHz$
4. For $V_{IN, \min} = 12.0V, F_{SW} = 980kHz$
4. For $V_{IN, \min} = 12.5V, F_{SW} = 981kHz$

In the end, for VersionV1.0, we deemed that battery will never continuously drop under 12.5V. The full range of frequency of the LM5160 cannot be used and we must ensure F_sw<981kHz. 

_Note1_: Raising the UVLO could protect from <12V on battery rail.

### Check minimal on time

Then, we have to check that the minimum on time (150ns typical) is low enough to ensure we can convert from the maximal tension. Let's take a fully charge 6S transient => 60V.

$F_{SW,\max(@V_{IN,\max})} = \frac{V_{OUT}}{V_{IN,\max} \cdot T_{ON,\min}} = 1.1MHz$ 

Thus, the full range frequency of the LM5160 can be used with a confortable margin as 60V whas considered in input.

### Conclusion

We will aim for F_sw = 900kHz. This is 900/128=7 times greater than the 128kHz max frequency of our PWM and well withing the 5-10x law of sampling rate, so there should be no issues.

$R_{\text{ON}} = \frac{V_{\text{OUT}}}{F_{\text{SW}} \times 10^{-10}} = 111k\Omega$, we will use $120k\Omega$ as it is the nearest value on JLCPCB, so 833kHz maximum.

$T_{\text{ON}, \text{typ}} = \frac{R_{\text{ON}} \times 10^{-10}}{V_{\text{IN}}} = 458ns$

On JLCPCB, there are no 110kR, so we went with a 120kR part, hence Fsw is limited to 833kHz, margin should be enough.

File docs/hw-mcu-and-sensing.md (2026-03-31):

# MCU & Sensing

## 🧠 MCU

The system is based on an stm32g474, selected for its strong analog integration and motor-control-oriented peripherals. It provides fast ADCs with injected conversions, advanced timers suited for high-frequency PWM, and integrated OPAMPs, which significantly reduce external components while improving signal quality and latency.

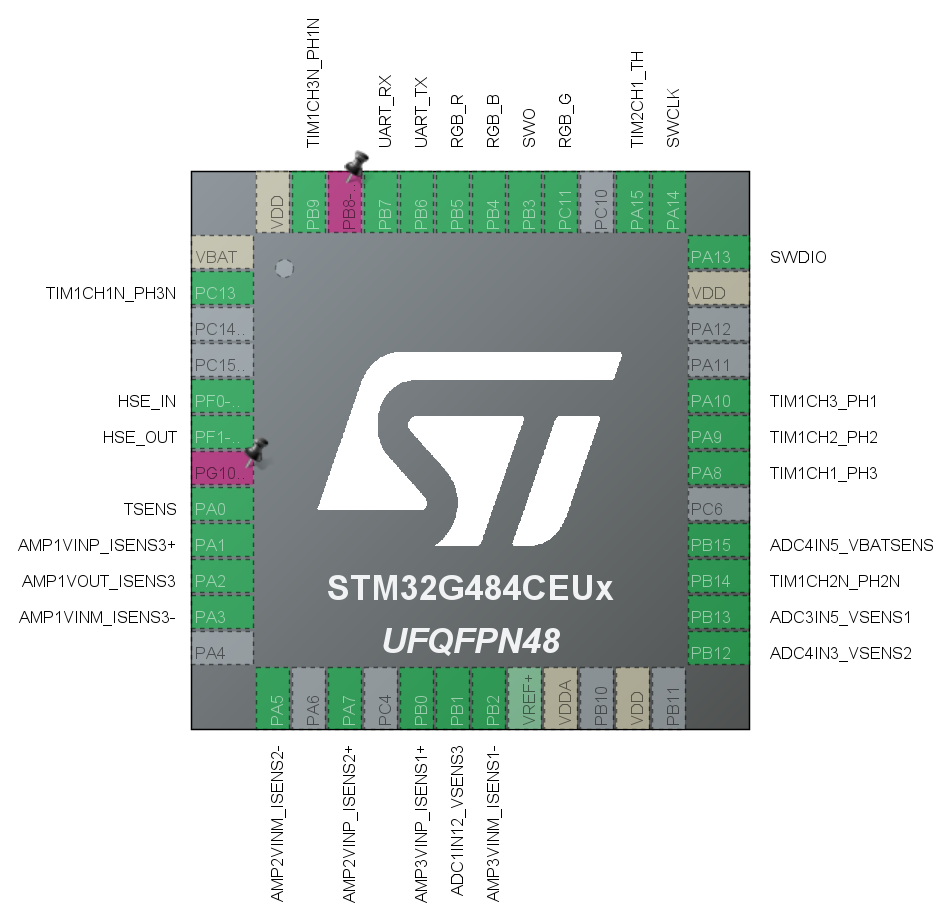
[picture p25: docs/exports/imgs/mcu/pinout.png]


Three sensing probes are implemented for both phase voltage and current. While this is not strictly required for FOC or six-step control, it was intentionally included in this first revision to allow full observability and validation of the system behavior. This provides better insight during bring-up, tuning, and debugging.

For current sensing, the signals are routed through internal OPAMPs. This ensures proper scaling of the shunt voltage and, more importantly, presents a low impedance to the ADC inputs, enabling fast and reliable sampling.

## 📡 Sensing

All signals are acquired through the ADC. When using an internal OPAMP, the ADC sees a low impedance source, enabling fast sampling. In contrast, direct measurements (e.g. resistive dividers) present a high impedance, so the effective input resistance $R_{AIN}$ must comply with STM32 ADC requirements (see `docs/exports/imgs/mcu/rain.png`). Detailed sizing is available in `docs/Kururugi-ESC-sizing.xlsx`.

### 🔋 Vsensbat

The battery voltage is measured using a resistive divider. A high resistance (22 kΩ) is used to reduce BOM and losses, but this results in a slow acquisition time (~408 µs at 12-bit). A 100 nF capacitor at the ADC input mitigates this by charging during blanking time.

### ⚡ VsensPh1 / Ph2 / Ph3

Phase voltages are measured using the same divider approach, with identical constraints and mitigation using a 100 nF capacitor. All three phases are currently measured, but future versions may reduce this to two.

### 🔌 Isens Ph1 / Ph2 / Ph3

Phase currents are measured using a 0.5 mΩ Kelvin shunt. The signal is routed as a differential pair to an internal OPAMP, which both amplifies it and provides a low impedance output to the ADC. All three phases are measured, but future versions may reduce this or move to VBAT sensing.

### 🌡️ Tsens

Temperature is measured using an NTC thermistor connected to the ADC through a resistive divider.

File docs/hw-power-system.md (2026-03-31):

# ⚡ Power System

## 🔋 VBAT

VBAT is supplied by a 4S to 6S battery. Input filtering is ensured by five 2.2 µF (3216) capacitors to mitigate cable-induced ringing [1], which can reach up to 45 V during transients.  

For V1.0, input protection remains minimal; additional Schottky diodes and improved ESD protection will be introduced in future revisions.

VBAT is monitored through a resistive divider connected to ADC5 Channel 1 (pin X). Dedicated test points are available for both VBAT and VSENSBAT measurements. The scaling is defined such that 25 V corresponds to approximately 1.1 V at the ADC input.

The acceptable operating limits for V1.0 are summarized below:

- Typical phase current (@ 95% ToF): 12.5 A  
- Maximum phase current (short duration): 20 A  
- Peak current spike (transient): 50 A  

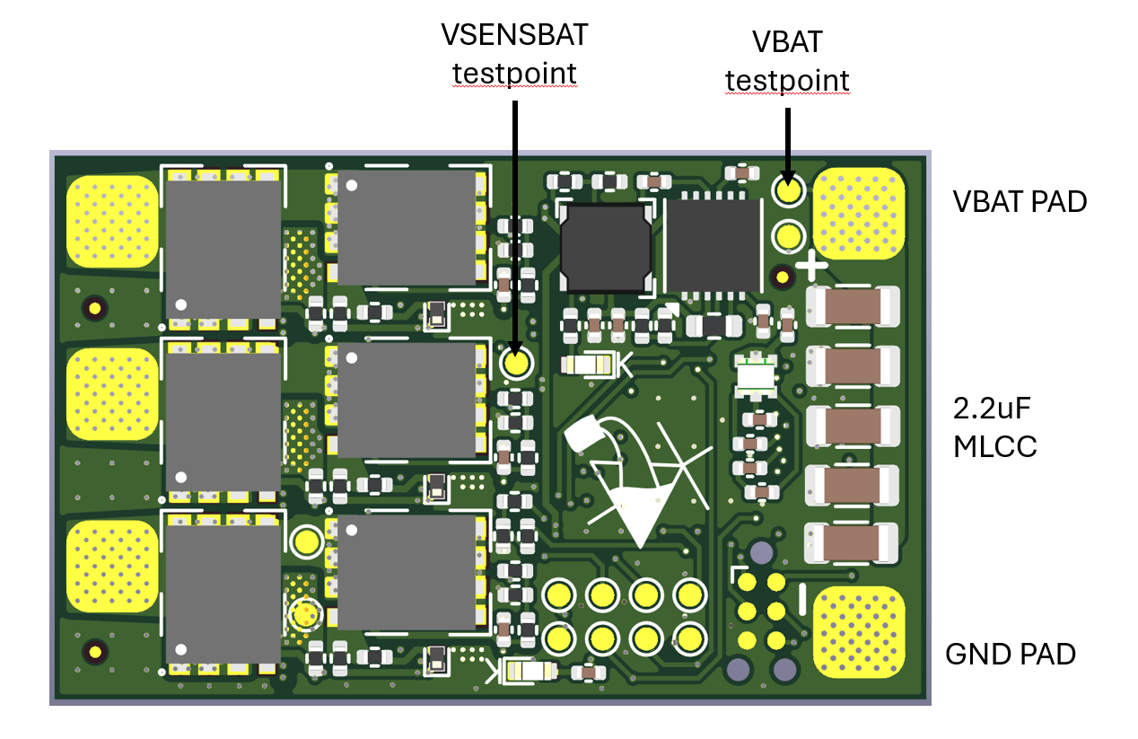
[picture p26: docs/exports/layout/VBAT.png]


## 🚪 VBUCK *(Work in progress)*

## 🔌 3V3 *(Work in progress)*

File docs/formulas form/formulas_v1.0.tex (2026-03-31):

\documentclass[a4paper, 10pt, conference]{IEEEtran} % Use this line for a4 paper

\usepackage{graphics} % for pdf, bitmapped graphics files
\usepackage{epsfig} % for postscript graphics files
\usepackage{mathptmx} % assumes new font selection scheme installed
\usepackage{times} % assumes new font selection scheme installed
\usepackage{amsmath} % assumes amsmath package installed
\usepackage{amssymb}  % assumes amsmath package installed

% Custom packages
\usepackage{algorithm}
\usepackage{algpseudocode} % pour avoir l'environnement algorithmic

\title{\LARGE \bf
--- Electronical Engineering Note --- \\
Engineering of a 94kHz 15A sensorless quadricopter ESC
}

\author{Stepane Binon and Guilhem Andrieu% <-this % stops a space
	\thanks{Bare Metal Foundry}
	\thanks{\tt\small stepane.binon@gmail.com}
}

\begin{document}

\maketitle
\thispagestyle{empty}
\pagestyle{empty}

\section{Design of the MOSFETs}

\[
P_{cond} = I_{ph,mean}^2*R_{DS,on}*D_{max}
\]
\[
P_{cond} = I_{ph,max}^2*R_{DS,on}*D_{max}
\]
\[
P_{switch,typ} = \frac{1}{2}V_{ph,spike@run}*I_{ph,mean}*F_{SW,max}(t_{rise}+t_{fall})
\]
\[
P_{switch,max} = \frac{1}{2}V_{ph,spike@run}*I_{ph,max}*F_{SW,max}(t_{rise}+t_{fall})
\]
\[
P_{tot,typ} = 2P_{cond,mean} + 4P_{switch,typ,spike}
\]
\[
P_{tot,max} = 2P_{cond,max
} + 4P_{switch,max,spike}
\]

\section{Design of the Half-Bridges}

\[
\Delta V_{boot,max} = V_{DD} - V_F - V_{HBR} - V_{HBH}
\]
\[
V_{boot,min} = V_{DD}-\Delta V_{boot,max}
\]
\[
V_{boot,max} = V_{DD}-V_f
\]
\[
I_{pulldown} = V_{boot,max} / R_{pulldown}
\]
\[
Q_{BS} = Q_g + \frac{I_{HB} + (I_{HBS} + I_{pulldown}) D_{max}}{F_{sw}}
\]
\[
C_{boot,min} \ge \frac{Q_{BS}}{\Delta V_{boot,max}}
\]
\[
C_{boot} = \frac{C_{boot,min}}{1-{k_{derating}}}*S_{C_{boot}}
\]
\[
t_{recharge} = \frac{1-D}{F_{SW}} - t_{blank@V_{SW}=0}
\]
\[
R_{eq} = \frac{  R_{boot,ext} * R_{boot,int}   }{    R_{boot,ext} + R_{boot,int} }
\]
\[
V_{boot,max @ D_{max}} = V_{boot,max} - (V_{boot,max} - V_{boot,min}) e^{-\frac{t_{recharge}}{R_{eq}C_{boot}*k_{derating}}}
\]
\[
P_{boot} = C_{boot}(1-k_{derating})V_{boot}\Delta V_{boot,max}F_{max}
\]
\[
P_{Rboot} = \frac{1}{2}C_{boot}(1-k_{derating})\Delta V_{boot,max}^2F_{max}
\]
\[
P_{Rboot,ext} = \frac{R_{boot,int}}{R_{boot,ext}+R_{boot,int}}P_{boot}
\]
\[
R_{eq,on} = \frac{R_{pu,hs}+R_{pu,ls}}{2} + R_{g,on+off} + R_{g,int}
\]
\[
R_{eq,off} = \frac{R_{pd,hs}+R_{pd,ls}}{2} + R_{g,eq,off} + R_{g,int}
\]
\[
I_{max,on} = V_{boot,max} / R_{eq,on}
\]
\[
I_{max,off} = V_{boot,max} / R_{eq,off}
\]
\[
I_{Miller,on} = V_{miller} / R_{eq,on}
\]
\[
I_{Miller,on} = V_{miller} / R_{eq,off}
\]
\[
t_{rise} = Q_g/I_{Miller,on}
\]
\[
t_{fall} = Q_g/I_{Miller,off}
\]
\[
P_{g,loss,min} = Q_g * V_{boot,max} * F_{SW}
\]
\[
P_{g,loss} = P_{g,loss,min}*S
\]
\[
P_{R_{GDint},mean} = P_{g,loss}-P_{Rg,mean}
\]
\[
P_{Rg,mean} = \frac{R_{g,mean}}{R_{g,mean}+R_{GD,mean}}*P_{g,loss}
\]
\[
P_{Rg,on+off} = \frac{1}{2}\left(1 + \frac{R_{g,off}}{R_{g,on+off}+R_{g,off}}\right)P_{Rg,mean}
\]
\[
P_{Rg,off} = P_{Rg,mean}-P_{Rg,on+off}
\]

\section{Design of the Current sensing}

\[
V_{shunt,typ} = R_{shunt} * I_{ph,typ}
\]
\[
V_{shunt,amp,typ} = V_{shunt,typ}*G_{opamp}
\]
\[
V_{shunt,spike} = R_{shunt} * I_{ph,spike}
\]
\[
V_{shunt,amp,spike} = V_{shunt,spike}*G_{opamp}
\]
\[
\Delta I_{LSB} = \frac{V_{ref,ADC}}{(2^{B_{res}}-1)*G_{opamp}*R_{shunt}}
\]
\[
P_{shunt,mean} = \frac{2}{3} * R_{shunt} * I_{ph,mean}^2 * D_{max}
\]
\[
P_{shunt,max} = \frac{2}{3} * R_{shunt} * I_{ph,max}^2 * D_{max}
\]

\section{Design of the Voltage sensing}

As the current sensing uses an op-amp buffer with very low output impedance, the ADC input impedance constraint becomes negligible. Therefore, detailed RC settling analysis at the ADC pin is not required for the current sensing ADC channels. As the ADC of the STM32G474 are designed for this purpose, no additional impedance matching or damping network is deemed necessary.
\[
R_{V_1} = R_{V_2}(\frac{V_{ph,spike}}{V_{ADC}} - 1)
\]
\[
P_{R_{V_1},R_{V_2}} = \frac{V_{ph,spike}^2}{R_{V_1}+R_{V_2}}
\]
\[
V_{divider,spike} = \frac{R_{V_2}}{R_{V_1}+R_{V_2}} V_{ph,spike}
\]
\[
V_{divider,typ} = \frac{R_{V_2}}{R_{V_1}+R_{V_2}} V_{ph,typ}
\]
\[
I_{divider,typ} = \frac{V_{divider,typ}}{R_{V_1}+R_{V_2}}
\]
\[
I_{in,ADC,spike} = \frac{V_{divier,spike}}{R_{adc,ext}}
\]
\[
I_{in,ADC,typ} = \frac{V_{divier,typ}}{R_{adc,ext}}
\]
\[
\Delta V_{LSB} = \frac{V_{ref,ADC}}{V_{in,ADC}(2^{N_{bit}}-1)}V_{ph,spike}
\]
\[
R_{thvn} = \frac{R_{V_1}*R_{V_2}}{R_{V_1}+R_{V_2}}
\]
As $R_{AIN} = 100\Omega \le R_{thvn}+R_{ADC,ext}$, a impedance matching network is required. We will rely on an external capacitor name $C_{ADC,ext}$.
\[
F_{c,C_{ADC,ext}} = \frac{1}{2\pi (R_{thvn}+R_{ADC,ext})C_{ADC,ext}}
\]
\[
C_{ADC,ext,real} = C_{ADC,ext}*(1-k_{derating})
\]
\[
\begin{aligned}
T_{fill,C_{ADC,ext}} &= S*\tau_{c,C_{ADC,ext,real}} \\
&= S*(R_{thvn}+R_{ADC,ext})C_{ADC,ext,real}
\end{aligned}
\]
\[
C_{ADC,tot} = C_{samp} + C_{pad} + C_{trace}
\]
\[
\begin{aligned}
T_{fill,samp} &= S*\tau_{c,C_{samp+pad}} \\
&= S*R_{pad}*(C_{samp}+C_{pad})
\end{aligned}
\]
To chose the external capacitor, one should note that we won't be sampling the ADC during blanking time. Hence, the external capacior will be fully charged at the start of the sampling: we can model the external capacitor as fully charge at the start of a sampling. This assumption holds when $t_{\mathrm{settle}} \gg R_{\mathrm{th}}\,C_{\mathrm{ext}}$.

\section{$V_{BAT}$ sensing}

\[
V_{BAT,ADC,max} = \frac{R2}{R1+R2} V_{ph,spike@disarm}
\]
\[
V_{BAT,ADC,typ} = \frac{R2}{R1+R2} V_{ph,typ}
\]
\[
R_{BAT,ADC,thevenin} = \frac{R2*R1}{R1+R2}
\]

\end{document}

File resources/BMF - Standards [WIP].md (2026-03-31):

# Rules BMT [Draft document]

This documents sums up the standard rules defined for the whole BARE METAL FOUNDRY.

## Component libraries in Kicad

#### Symbol properties minimal set of properties 

1. Manufacturer
2. Manufacturer Part Number
3. Supplier Link 1
4. Supplier Link 2
5. LCSC

For symbols visibles only on the symbol editor of kicad, labels must be shown ('Show name' must be ticked)

## Documentation

Each project must be documented. Here are the accepeted formats and the expected content
- Calculus sheets [EXCEL]: provide calculus sheet and project managment, must have a introduction sheet to present its content (template must be built)
- Paper/Serious review PDF [LATEX]:  provide robustness but is tidious to use, also add boilerplate to the git repo, we must find a way to manage that
- Review/fast report [WORD]: what you see is what you get, just faster than Latex
- Presentation [POWERPOINT]: 
- Code and git documenetation [MARKDOWN]: a markdown is too weak for a deep documentation and not easy to read. Thus it is only used as **a concise summary with helpful ressources**.

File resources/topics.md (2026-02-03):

# Topipcs

Below are listed some interesting topic regarding the building of an ESC:
 - https://www.reddit.com/r/PrintedCircuitBoard/comments/1qg29i4/review_request_bldc_foc_controller/#lightbox
 - https://oshwhub.com/lyh6767/32-bit-four-in-one-esc-4in1-esc
 - https://electronoobs.com/eng_arduino_tut91.php?utm_source=chatgpt.com

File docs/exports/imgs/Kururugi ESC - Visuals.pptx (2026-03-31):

## Kururugi ESC – Visuals

Stepane Binon – 31/03/2026

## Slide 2

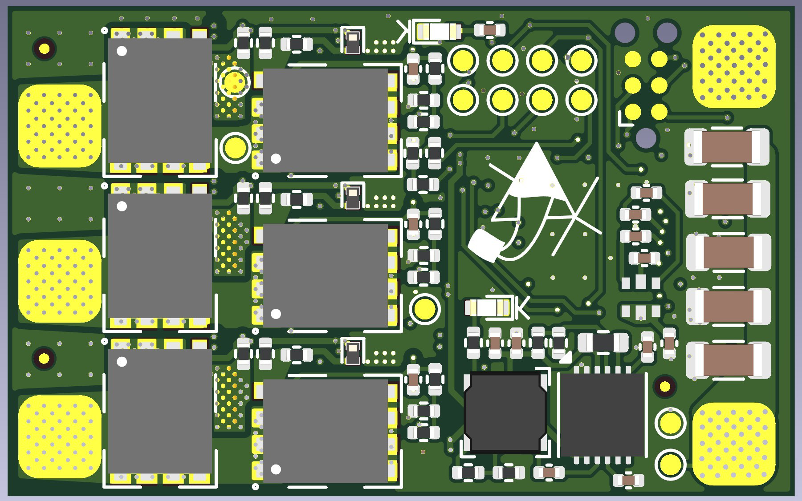
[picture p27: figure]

VGATE LED

Power Stage: The 3 half bridges

3xVoltage and 1xtemp sensing

Probing zone

Battery conections

Vbat Filtering

RGB Debug LED

BLDC conections

3V3 LED

Buck (VBAT -> VGATE)

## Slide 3

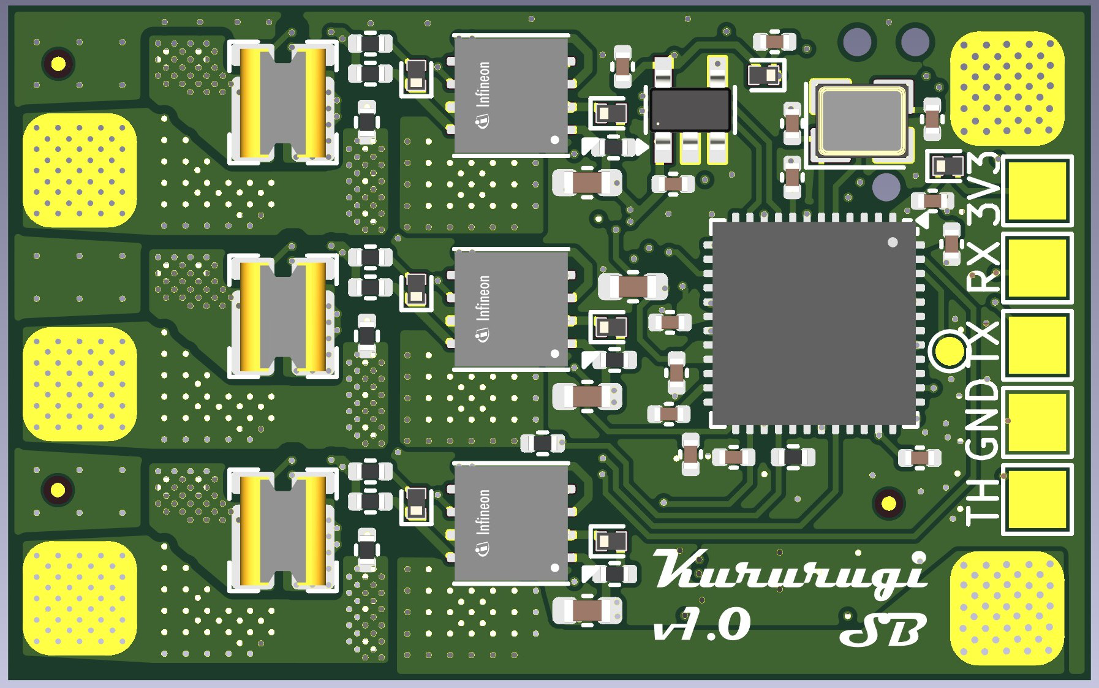
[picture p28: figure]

Gate driver: For MOSFET driving

VBAT sensing

Shunts: For current sensing

LDO: 5V stage

Crystal: 5V stage

Auxilary 3V3

UART

Throttle command:
PWM/DShot

MCU – STM32G484

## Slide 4

VSENSBAT testpoint

VBAT testpoint


VBAT PAD

2.2uF MLCC

GND PAD

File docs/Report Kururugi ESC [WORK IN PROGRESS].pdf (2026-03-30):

## Kururugi ESC Design and Sizing Report

Your Name

March 31, 2026

### Contents

1 Introduction | 3
2 System Overview | 3
3 Electrical sizing | 4
4 Schematic Design | 4
5 PCB Design | 5
6 Conclusion | 6
A Component List | 6

B Calculation Notes | 6
C Figures and Schematics | 6

Abstract

This document presents the design, sizing, schematic capture, and PCB implementation of the Kururugi ESC. The objective is to justify the main design choices, validate the electrical calculations, and document the final hardware implementation. To speed up the process, this document was co-written with an AI assistant.

### 1 Introduction

### 1.1 Project context

Electronic Speed Controllers (ESCs) are critical components in electric propulsion systems, converting battery power into controlled three-phase signals to drive brushless DC (BLDC) motors. In high-performance applications such as FPV drones, ESCs must operate under demanding conditions including high current peaks, fast switching frequencies, limited PCB area, and strong electromagnetic constraints.
This project focuses on the design of a compact and high-performance ESC tailored for aggressive drone operation. The target system requires reliable operation over a wide input voltage range (4S to 6S LiPo), high efficiency at elevated switching frequencies, and precise current sensing for advanced motor control strategies.
Beyond its functional objective, this ESC was also developed as a foundational learning project to gain hands-on experience in PCB design and low-level embedded development. It is conducted alongside the Shirley-FC development board (https://github.com/Gui-arain/Shirley-FC-Dev-Board/tree/main/resources) by Guilhem Andrieu, forming a coherent hardware and firmware development platform.
These projects aim to serve as the technological basis for the development of fast, fully autonomous drones, and constitute the initial building blocks of the Bare Metal Foundry, an initiative focused on mastering embedded systems from hardware to high-level software.

### 1.2 Objectives

The objective of this project is to design a compact ESC for a 6-inch FPV drone, capable of reliable operation under high electrical and dynamic stress.
The ESC must operate from 13–25.2 V, with tolerance to voltage spikes up to 45 V (battery) and 35 V (phase). It shall sustain continuous phase currents of 12.5–15 A, with peaks up to 20–25 A and transient spikes up to 50–60 A. High-frequency operation is targeted, up to 64 kHz (V1.0) and 96 kHz (V2), with duty cycles up to 90–95%.
Thermally, the design must ensure safe operation through proper loss distribution, efficient PCB heat spreading, and temperature monitoring using a thermistor. Mechanically, the ESC must fit a compact layout with minimized power loops and compatibility with standard drone integration.
Functionally, it must provide accurate sensing, robust transient behavior, and support low-level firmware for high-performance motor control.

### 2 System Overview

### 2.1 Functional description

The ESC converts DC battery power into controlled three-phase signals to drive a BLDC motor. It regulates motor speed and torque through high-frequency PWM, while monitoring current, voltage, and temperature to ensure safe and efficient operation.
The system integrates power conversion, control, sensing, and protection functions within a compact PCB suitable for FPV drone applications.

### 2.2 Top-level architecture

The ESC is organized around the following main blocks:
- STM32G4 MCU: control, PWM, acquisition
- Gate driver: MOSFET control
- Three-phase bridge: power stage
- Sensing: current, voltage, temperature
- Power supplies: regulated rails
- Interfaces: UART, JTAG (debug/config)

### 2.3 Main design specifications

Table 1: Main design specifications

Parameter | Value / Description
Input voltage | 13–25.2 V nominal (4S–6S LiPo), up to 45 V transient
Continuous current | 12.5–15 A per phase
Peak current | 20–25 A short duration, up to 50–60 A transient
PWM frequency | Up to 64 kHz (V1.0), 96 kHz (V2)
Control MCU | STM32G4 series (advanced timers, ADC, op-amps)
Gate driver | Infineon 2EDL8024
MOSFETs | Low RDS(on) N-channel power MOSFETs (e.g. 60 V class)
PCB dimensions | Compact ESC form factor for 6-inch drone (approx. 30 mm class)

### 2.4 Design inputs and assumptions

The first hardware revision targets a 4S–6S LiPo FPV ESC. The main design assumptions are:
- Input voltage from 13–25.2 V, with transients up to 45 V (battery) and 35 V (phase),
- Gate-driver supply around 10 V,
- PWM frequency up to 64 kHz (V1.0), with higher frequencies as future targets,
- Maximum duty cycle up to 95%,
- Phase current in the 12.5–15 A range, with higher transient peaks,
- Conservative derating for temperature and MLCC DC bias.
A 10 V rail is generated from VBAT via a buck converter and post-regulated to 3.3 V for logic.

### 3 Electrical sizing

Please refer to the sizing Excel.

### 4 Schematic Design

### 4.1 Schematic organization

The schematic is structured into functional blocks reflecting the system architecture: power stage, gate driver, sensing, power supply, and control. This modular approach improves readability, reuse, and validation of each subsystem.

### 4.2 Gate driver and power stage

The power stage consists of a three-phase MOSFET bridge driven by the Infineon 2EDL8024 gate driver. Each half-bridge integrates bootstrap circuitry and asymmetric gate resistors to control switching speed and mitigate EMI. Particular attention is given to minimizing parasitic inductance in the switching loops and ensuring reliable high-duty-cycle operation.

### 4.3 Sensing circuits

Current sensing is implemented using low-value shunt resistors with analog amplification before ADC acquisition. Voltage sensing relies on resistive dividers with local RC filtering to ensure accurate sampling under fast switching conditions. Temperature monitoring is achieved using an NTC thermistor placed near a power MOSFET, enabling thermal supervision and derating.

### 4.4 Power supply section

The power supply is divided into two stages: a buck converter generating a 11.5 V intermediate rail from VBAT, followed by an LDO providing a clean 3.3 V rail for the MCU and analog circuits. Decoupling is applied locally at each critical node to ensure stability and reduce noise coupling. The 11.5V guarantee that, even with voltage drop from the overall circuit, the gate are driven at 10V, ensure rapid switching and thus minimizing switching losses.

### 4.5 Microcontroller section

The design uses an STM32G4 microcontroller, leveraging advanced timers for PWM generation and ADCs for synchronized measurements. Internal op-amps and comparators are used where appropriate to reduce external component count. Standard interfaces such as UART and JTAG are included for communication and debugging.

### 4.6 Protection and robustness features

The schematic integrates protection mechanisms including input voltage filtering, undervoltage lockout through the power stage, and careful layout of sensitive analog nodes. RC filtering and proper decoupling are used to mitigate switching noise. The design also considers robustness against transient events such as arming/disarming and load steps.

### 4.7 Design review summary

The schematic reflects a trade-off between performance, compactness, and robustness. Low RDS(on) MOSFETs reduce conduction losses but increase switching constraints, requiring careful gate-drive design. Analog sensing accuracy is balanced against noise sensitivity, and the power architecture prioritizes clean supply rails over maximum efficiency. Overall, the design is consistent with the targeted operating conditions and provides a solid foundation for PCB implementation.

### 5 PCB Design

### 5.1 Board constraints and objectives

[TODO: Size, layer count, current capability, manufacturability.]

### 5.2 Stack-up definition

[TODO: Describe layers and their functions.]

### 5.3 Component placement strategy

[TODO: Critical loops, thermal distribution, accessibility.]

### 5.4 Power routing

[TODO: Phase paths, battery paths, copper width, polygon use, via stitching.]

### 5.5 Signal routing

[TODO: Gate signals, ADC traces, sensitive nets, debug interfaces.]

### 5.6 Grounding strategy

[TODO: Power ground vs quiet ground, return paths, stitching.]

### 5.7 Thermal design features

[TODO: Copper areas, thermal vias, heat spreading.]

### 5.8 Manufacturing and assembly considerations

[TODO: Courtyard, clearances, fiducials, test pads, DFM choices.]

### 5.9 PCB review summary

[TODO: Main layout achievements and remaining limitations.]

### 6 Conclusion

### 6.1 Summary of the design

[TODO: Summarize the final ESC design and key results.]

### 6.2 Main challenges and tradeoffs

[TODO: Discuss compromises made in sizing, schematic, and PCB.]

### 6.3 Future improvements

[TODO: Possible hardware and firmware improvements.]

### A Component List

[TODO: Optional: add main BOM table.]

### B Calculation Notes

[TODO: Optional: add extra derivations not kept in main text.]

### C Figures and Schematics

[TODO: Optional: full-page schematic or PCB images.]

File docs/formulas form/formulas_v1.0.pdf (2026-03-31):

# — Electronical Engineering Note — Engineering of a 94kHz 15A sensorless quadricopter ESC

## Stepane Binon and Guilhem Andrieu

I. DESIGN OF THE MOSFETS

Pcond = I

2
ph,mean ∗RDS,on ∗Dmax

Pcond = I

2
ph,max ∗RDS,on ∗Dmax

Pswitch,typ =

1
2

Vph,spike@run ∗ Iph,mean ∗FSW,max(trise +tf all)

Pswitch,max =

1
2

Vph,spike@run ∗ Iph,max ∗FSW,max(trise +tf all)

Ptot,typ = 2Pcond,mean +4Pswitch,typ,spike

Ptot,max = 2Pcond,max +4Pswitch,max,spike

II. DESIGN OF THE HALF-BRIDGES

∆Vboot,max = VDD −VF −VHBR −VHBH

Vboot,min = VDD −∆Vboot,max

Vboot,max = VDD −Vf

Ipulldown = Vboot,max/Rpulldown

QBS = Qg +

IHB + (IHBS +Ipulldown)Dmax

Fsw

Cboot,min ≥

QBS

∆Vboot,max

Cboot =

Cboot,min

1−kderating

∗ SCboot

trecharge =

1−D

FSW

−tblank@VSW =0

Req =

Rboot,ext ∗Rboot,int

Rboot,ext +Rboot,int

Vboot,max@Dmax =Vboot,max−(Vboot,max−Vboot,min)e

−

t
recharge
ReqCboot ∗kderating

Pboot = Cboot(1−kderating)Vboot∆Vboot,maxFmax

PRboot =

1
2

Cboot(1−kderating)∆V

2
boot,maxFmax

PRboot,ext =

Rboot,int

Rboot,ext +Rboot,int

Pboot

Req,on =

Rpu,hs +Rpu,ls
2

+Rg,on+o f f +Rg,int

Req,o f f =

Rpd,hs +Rpd,ls
2

+Rg,eq,o f f +Rg,int

Imax,on = Vboot,max/Req,on

Imax,o f f = Vboot,max/Req,o f f

IMiller,on = Vmiller/Req,on

IMiller,on = Vmiller/Req,o f f

trise = Qg/IMiller,on

tf all = Qg/IMiller,o f f

Pg,loss,min = Qg ∗Vboot,max ∗FSW

Pg,loss = Pg,loss,min ∗ S

PRGDint ,mean = Pg,loss −PRg,mean

PRg,mean =

Rg,mean

Rg,mean +RGD,mean

∗Pg,loss

PRg,on+o f f =

1
2
1+

Rg,o f f

Rg,on+o f f +Rg,o f f
PRg,mean

PRg,o f f = PRg,mean −PRg,on+o f f

III. DESIGN OF THE CURRENT SENSING

Vshunt,typ = Rshunt ∗ Iph,typ

Vshunt,amp,typ = Vshunt,typ ∗Gopamp

Vshunt,spike = Rshunt ∗ Iph,spike

Vshunt,amp,spike = Vshunt,spike ∗Gopamp

∆ILSB =

Vre f,ADC
(2

Bres −1) ∗Gopamp ∗Rshunt

Pshunt,mean =

2
3

∗Rshunt ∗ I

2
ph,mean ∗Dmax

Pshunt,max =

2
3

∗Rshunt ∗ I

2
ph,max ∗Dmax

IV. DESIGN OF THE VOLTAGE SENSING

As the current sensing uses an op-amp buffer with very low output impedance, the ADC input impedance constraint becomes negligible. Therefore, detailed RC settling analysis at the ADC pin is not required for the current sensing ADC channels. As the ADC of the STM32G484 are designed for this purpose, no additional impedance matching or damping

network is deemed necessary.

## RV1 = RV2

(

Vph,spike

VADC

−1)

## PRV1

,RV2

=

V

2
ph,spike

## RV1 +RV2

Vdivider,spike =

RV2

## RV1 +RV2

Vph,spike

Vdivider,typ =

RV2

## RV1 +RV2

Vph,typ

Idivider,typ =

Vdivider,typ

## RV1 +RV2

Iin,ADC,spike =

Vdivier,spike

Radc,ext

Iin,ADC,typ =

Vdivier,typ

Radc,ext

∆VLSB =

Vre f,ADC

Vin,ADC(2

Nbit −1)

Vph,spike

Rthvn =

RV1

∗RV2

## RV1 +RV2

## As RAIN = 100Ω ≤ Rthvn + RADC,ext, a impedance matching network is required. We will rely on an external capacitor

name CADC,ext.

Fc,CADC,ext =

1

2π(Rthvn +RADC,ext)CADC,ext

CADC,ext,real = CADC,ext ∗ (1−kderating)

Tfill,CADC,ext = S ∗ τc,CADC,ext,real

= S ∗ (Rthvn +RADC,ext)CADC,ext,real

CADC,tot = Csamp +Cpad +Ctrace

Tfill,samp = S ∗ τc,Csamp+pad

= S ∗Rpad ∗ (Csamp +Cpad)

## To chose the external capacitor, one should note that we

won’t be sampling the ADC during blanking time. Hence,

## the external capacior will be fully charged at the start of the sampling: we can model the external capacitor as fully charge at the start of a sampling. This assumption holds when

tsettle ≫ RthCext.

V. VBAT SENSING

VBAT,ADC,max =

R2
R1+R2

Vph,spike@disarm

VBAT,ADC,typ =

R2
R1+R2

Vph,typ

RBAT,ADC,thevenin =

R2 ∗R1
R1+R2

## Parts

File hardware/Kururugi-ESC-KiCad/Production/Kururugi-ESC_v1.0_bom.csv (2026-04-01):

Designator | Footprint | Quantity | Value | LCSC Part #
C1, C2, C3, C4, C5 | 1206 | 5 | 2.2u | C50254
C10, C11, C13, C14, C18, C21, C22 | 0402 | 7 | 1u | C52923
C12, C16 | 0402 | 2 | 10n | C15195
C15, C23, C24, C27, C30, C33, C6, C7, C8, C9 | 0402 | 10 | 100n | C1525
C17, C26, C29, C32 | 0603 | 4 | 1u | C15849
C19, C20 | 0402 | 2 | 10p | C32949
C25, C28, C31 | 0402 | 3 | 220n | C16772
D1, D4 | 0603 | 2 | KT-0603W | C2290
D10, D11, D12, D13, D2, D3, D5, D6, D7, D8, D9 | Rohm_SMD1006 | 11 | RB161QS-40T18R | C2837790
J1, J10, J11, J2, J9 | Phase4x4 | 5 | Conn_01x01
J3, J4, J5, J6, J7 | TestPoint_Pad_2.0x2.0mm | 5 | Conn_01x01
L1 | LVS404018-220M-N | 1 | 22u | C116614
LED1 | SMD-B_19-337C_EVE | 1 | 19-337C/RSBHGHC-A88/4T | C3019536
Q1, Q2, Q3, Q4, Q5, Q6 | CSD18540Q5B | 6 | CSD18540Q5B | C86513
R1, R8 | 0402 | 2 | 22k | C25768
R10, R13, R14, R15, R16 | 0402 | 5 | 100 | C25076
R11, R20, R23, R24, R31, R34, R35, R42, R45, R46 | 0402 | 10 | 10k | C25744
R12, R2, R26, R37, R48 | 0402 | 5 | 33 | C25105
R17, R19, R21, R28, R30, R32, R39, R41, R43 | 0402 | 9 | 3.3 | C25165
R18, R22, R29, R33, R40, R44 | 0402 | 6 | 10 | C25077
R25, R36, R47 | HoBB1216-5W-0.5mR-1 | 3 | 0.5m | C17701556
R27, R3, R38, R49, R6 | 0402 | 5 | 1k | C11702
R4 | 0603 | 1 | 120k | C25808
R5 | 0402 | 1 | 200k | C25764
R7 | 0402 | 1 | 51k | C25794
R9 | 0402 | 1 | 12k | C25752
TH1 | 0402 | 1 | Thermistor_NTC | C209959
TP1, TP10, TP11, TP12, TP13, TP2, TP3, TP4, TP5, TP6, TP7, TP8, TP9 | TestPoint_Pad_D1.0mm | 13 | TestPoint
U1 | STM32G474CEU6 | 1 | STM32G474CEU6 | C1235412
U2 | LM5160ADNTR | 1 | LM5160A | C473375
U3 | TI-SOT-23 (5p) | 1 | TPS7B92033 | C32353919
U4, U5, U6 | 2EDL8024 | 3 | 2EDL8024 | C3655215
X1 | YXC-X322516MLB4SI | 1 | 16MHz | C13738

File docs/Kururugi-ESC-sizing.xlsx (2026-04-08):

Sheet: HMI
LIMITS |  | Gate Driver |  | MOSFET |  | Rshunt & ADC/OpAmp Isense |  | Rv2 & Rtrace |  | VBAT sensing
Version: |  | Infineon 2EDL8024 |  | Reference: |  | Chose the part: |  | Input data: |  | Input data:
V1.0 |  | Input data: |  | TI CSD18540Q5B |  | STM32G4 internal |  | Rv2 name | 1kΩ, 1005m | R1 name | 22kΩ, 1005m
Frame size (") | 6 | Vdd (V) | 10.5 | Vds (V) | 60 | Vmax (V) | 3.6 | Prated@70°C (mW) | 65 | R2 name | 1kΩ, 1005m
Dmax (%) | 90 |  |  | Qg,typ @ 10V (nC) | 41 | Input data: |  | Radc,ext name | 33Ω, 1005m | Computed data:
Fmax (kHz) | 64 | Diode - Dboot |  | Qg,typ,sync @ 10V (nC) (not used) | X | Rshunt (µΩ) | 500 | Prated@70°C (mW) | 65 | Vbat,adc,max (V) | 1.96
Vbat,min (V) | 14 | Rohm RB161QS-40 |  | Rds,on@10V typ(mΩ) (not used) | 1.8 | Resolution (bit) | 12 |  |  | Vbat,adc,typ (V) | 1.10
Vbat,typ (V) | 25.2 |  |  | Rds,on@10V max (mΩ) | 2.2 | Nsamp (cycle) | 2.5 | ADC Vsense |  | Rbat,adc,thev (Ω) | 956.5217391
Vbat spike (V) @ run | 32 | Rpull-down,gate |  | Id @ Tc>70°C (A) | 100 | OpAmp gain | 64 | Chose the part:
Vbat spike (V) @ disarm | 45 | Input data: |  | Id @ Ta>70°C (A) | (est ~21A) | Computed data: |  | STM32G4 internal
Vph spike (V) @ run | 35 | Rpd,gate (kΩ) | 10 | Size (mm) | 5x6 | ADC conversion time (ns) | 250.0 | Csamp (pF) | 5
Vph spike (V) @ disarm | 28 |  |  | JLCPBC stock | Yes | Vshunt,amp,spike (V) | 1.6 | Cpad (pF) | 5
Iph typ (A) @ 95% ToF | 12.5 | Cboot & Rboot,ext |  | Computed data: |  | ΔIlsb (mA/bit) | 25.2 | Input data:
Iph max (A@Xs) @ 4.9% ToF | 20 | Input data: |  | Ptot,typ (mW) | 1667.22 | Pshunt,mean (mW) | 50.0 | Resolution (bit) | 8
Iph spike (A@Xms) @ 0.1% ToF | 50 | Expected derating max (%) | 60 | Ptot,max (mW) | 3145.76 | Pshunt,max (mW@Xs) | 120.0 | Nsamp (cycle) | 2.5
Iph mean (A) | 12.9 | Expected derating min (%) | 30 |  |  |  |  | Ctrace,est (pF) | 5
Termistors | 1 (at a FET) | Safety margin on Cboot | 3.0 |  |  |  |  | Computed data:
Input data: |  | Rboot,ext (Ω) | 3.3 |  |  |  |  | ADC conversion time (ns) | 183.3
Min blank time (ns) | 480 | Computed data: |  |  |  |  |  | Rv1,th (Ω) | 9606.06
t_blank@V_sw=0 (ns) | 300 | Vboot,min (V) | 6.74 |  |  |  |  | Rv1 (Ω) | 10000.00
 |  | Vboot,max (V) | 10.26 |  |  |  |  | Vdivider,typ (V) | 2.29
 |  | Cboot,th (nF) | 167.4409907 |  |  |  |  | Vdivider,spike (V) | 3.18
 |  | Cboot (nF) | 180 |  |  |  |  | Idivider,typ (mA) | 2.29
 |  | Prboot (mW) | 49.41775277 |  |  |  |  | ΔVlsb,fullscale (mV/bit) | 142.3529412
 |  | t_recharge (µs) | 1.3 |  |  |  |  | Prv1,rv2 (mW) | 111.3636364
 |  | Vboot,max@Dmax (V) | 10.26 |  |  |  |  | Rthvn (Ω) | 909.0909091
 |  | Gate resistors |  |  |  |  |  | Cadc,ext
 |  | Input data: |  |  |  |  |  | Input data:
 |  | Rg,on+off (Ω) | 3.3 |  |  |  |  | Cadc,ext (pF) | 100
 |  | Rg,off (Ω) | 10 |  |  |  |  | Expected derating (%) | 40
 |  | Safety margin on losses | 1.5 |  |  |  |  | Charge factor (int) | 12
 |  | Computed data: |  |  |  |  |  | Charge factor (ext) | 5
 |  | Ig,max,on (A) | 1.7 |  |  |  |  | Computed data:
 |  | Ig,max,off (A) | 2.3 |  |  |  |  | Cadc,ext,real (pF) | 60
 |  | t_rise (ns) | 9.9 |  |  |  |  | Tfill,adc,ext (ns) | 282.6272727
 |  | t_fall (ns) | 7.5 |  |  |  |  | Tfill,samp (ns) | 169.5763636
 |  | Pg,loss (mW) | 40.4 |  |  |  |  | Radc,int < Rain as we use an external capaciot
 |  | Prg,on+off (mW) | 27.4 |  |  |  |  | Tfillsam just give a rought too conservative approx
 |  | Prg,off (mW) | 3.9
 |  | Prgdint,mean (mW) | 9.1

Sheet: CAL_Cboot
 |  | Vdd (V) | 10.5 | Qg,typ @ 10V (nC) | 41 | Safety margin on Cboot | 3 | Vboot,max (V) | 10.3
LIMITS |  | Vhbr (V) | 6 | Ihb (mA) | 0.7 | Expected derating max (%) | 60 | Vboot,min (V) | 6.7
Name | V1.0 | Vhbh,max (V) | 0.5 | Ihbs (mA) | 1.25 | Cboot,th (nF) | 167.4409907 | t_recharge (µs) | 1.3
Dmax (%) | 90 | Vf (V) | 0.24 | Ipd (mA) | 1.0 | Cboot (nF) | 180 | Req (Ω) | 2.9
Fmax (kHz) | 64 | ΔVboot,max (V) | 3.8 | Dmax (%) | 90 |  |  | Cboot (nF) | 167.4409907
t_blank@V_sw=0 (ns) | 300 |  |  | Fmax (kHz) | 64 |  |  | Expected derating max (%) | 60
GD |  |  |  | Qbs (nC) | 83.94375 |  |  | Vboot,max@Dmax (V) | 10.26
Ref | Infineon 2EDL8024
Vfint,100mA (V) | 2.1 | Vdd (V) | 10.5 |  |  | Dmax (%) | 90
Vhbr (V) | 6 | ΔVboot,max (V) | 3.76 |  |  | Fmax (kHz) | 64
Vhbh,max (V) | 0.5 | Vboot,min (V) | 6.74 |  |  | t_blank@V_sw=0 (ns) | 300 | Cboot (nF) | 180
Vdd (V) | 10.5 |  |  | Qbs (nC) | 83.94375 | t_recharge (µs) | 1.26 | Expected derating min (%) | 30
Ihb (mA) | 0.7 |  |  | ΔVboot,max (V) | 3.76 |  |  | ΔVboot,max (V) | 3.76
Ihbs (mA) | 1.25 |  |  | Cboot,min (nF) | 22.32546543 |  |  | Fmax (kHz) | 64
Rboot,int (Ω) | 21.5 | Vdd (V) | 10.5 |  |  |  |  | Pboot (mW) | 57.0028032
Cboot |  | Vf (V) | 0.24
Expected derating max (%) | 60 | Vboot,max (V) | 10.26 |  |  | Rboot,ext (Ω) | 3.3
Expected derating min (%) | 30 |  |  |  |  | Rboot,int (Ω) | 21.5
Safety margin on Cboot | 3 |  |  | Basic JLCPCB capacitances |  | Req (Ω) | 2.860887097 | Rboot,ext (Ω) | 3.3
Dext,boot |  |  |  | 47 |  |  |  | Rboot,int (Ω) | 21.5
Ref | Rohm RB161QS-40 | Vboot,max (V) | 10.26 | 56 |  |  |  | Pboot (mW) | 57.0028032
Vf@100mA (V) | 0.24 | Rpd,gate (kΩ) | 10 | 68 |  |  |  | Prboot (mW) | 49.42
Rpull-down,gate |  | Ipd (mA) | 1.03 | 82
Rpd,gate (kΩ) | 10 |  |  | 100
Rboot,ext |  |  |  | 120
Rboot,ext (Ω) | 3.3 |  |  | 150
MOSFET |  |  |  | 180
Ref | TI CSD18540Q5B |  |  | 220
Qg,typ @ 10V (nC) | 41 |  |  | 470
 |  |  |  | 680
 |  |  |  | 1000

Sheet: CAL_Fets
 |  | Iph mean (A) | 12.9
LIMITS |  | Iph max (A@Xs) @ 4.9% ToF | 20
Name | V1.0 | Rds,on@10V max (mΩ) | 2.2
Vbat,typ (V) | 25.2 | Dmax (%) | 90
Iph mean (A) | 12.9 | Pcond,mean (mW) | 329.7472695
Iph max (A@Xs) @ 4.9% ToF | 20 | Pcond,max (mW) | 792
Vph spike (V) @ run | 35
Dmax (%) | 90
Fmax (kHz) | 64
MOSFET
Part | TI CSD18540Q5B | Vph spike (V) @ run | 35
Rds,on@10V max (mΩ) | 2.2 | Iph mean (A) | 12.9
Gate driving |  | Iph max (A@Xs) @ 4.9% ToF | 20
t_rise (ns) | 9.9 | Fmax (kHz) | 64
t_fall (ns) | 7.5 | t_rise (ns) | 9.9
 |  | t_fall (ns) | 7.5
 |  | Psw,typ (mW) | 251.9318854
 |  | Psw,max (mW) | 390.4407368
 |  | Pcond,mean (mW) | 329.7472695
 |  | Pcond,max (mW) | 792
 |  | Psw,typ (mW) | 251.9318854
 |  | Psw,max (mW) | 390.4407368
 |  | Ptot,typ (mW) | 1667.222081
 |  | Ptot,max (mW) | 3145.762947

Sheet: CAL_Rg
 |  | Rg,off (Ω) | 10.0 | Vboot,max (V) | 10.26 | Qg,typ @ 10V (nC) | 41 | Rg,mean (Ω) | 1.61
LIMITS |  | Rg,on+off (Ω) | 3.3 | Req,on (Ω) | 5.9 | Vboot,max (V) | 10.26 | Rgatedriver,mean (Ω) | 0.47
Name | V1.0 | Rg,eq,off | 2.5 | Req,off (Ω) | 4.5 | Fmax (kHz) | 64.0 | Pg,loss (mW) | 40.4
Dmax (%) | 90 |  |  | Ig,max,on (A) | 1.74 | Pg,loss,min (mW) | 26.9 | Prg,mean (mW) | 31.23536906
Fmax (kHz) | 64 |  |  | Ig,max,off (A) | 2.28
GATE RESISTOR
Rg,off (Ω) | 10
Rg,on+off (Ω) | 3.3 | Rpu,hs (Ω) | 1 |  |  | Pg,loss,min (mW) | 26.92224
GATE DRIVER |  | Rpu,ls (Ω) | 1 |  |  | Safety margin on losses | 1.5 | Rg,off (Ω) | 10
Ref | Infineon 2EDL8024 | Rg,on+off (Ω) | 3.3 |  |  | Pg,loss (mW) | 40.38336 | Rg,on+off (Ω) | 3.3
Rpu,hs (Ω) | 1 | Rg,int,max (Ω) | 1.6 | Vmiller (V) | 4 |  |  | Prg,mean (mW) | 31.23536906
Rpu,ls (Ω) | 1 | Req,on (Ω) | 5.9 | Req,on (Ω) | 5.9 |  |  | Prg,on+off (mW) | 27.4
Rpd,hs (Ω) | 0.5 |  |  | Req,off (Ω) | 4.5
Rpd,ls (Ω) | 0.35 |  |  | Imiller,on (A) | 0.68 | Dmax (%) | 90
Vboot,max (V) | 10.26 |  |  | Imiller,off (A) | 0.89 | Rpu,hs (Ω) | 1
Cboot (nF) | 180 |  |  |  |  | Rpu,ls (Ω) | 1
Safety margin on losses | 1.5 | Rpd,hs (Ω) | 0.5 |  |  | Rpd,hs (Ω) | 0.5 | Prg,mean (mW) | 31.23536906
MOSFET |  | Rpd,ls (Ω) | 0.35 |  |  | Rpd,ls (Ω) | 0.35 | Prg,on+off (mW) | 27.36030448
Ref | TI CSD18540Q5B | Rg,eq,off | 2.5 |  |  | Rgatedriver,mean (Ω) | 0.5 | Prg,off (mW) | 3.9
Qg,typ @ 10V (nC) | 41 | Rg,int,max (Ω) | 1.6
Qgd,typ (nC) | 6.7 | Req,off (Ω) | 4.5 | Qgd,typ (nC) | 6.7
Vmiller (V) | 4 |  |  | Imiller,on (A) | 0.68
Rg,int,max (Ω) | 1.6 |  |  | Imiller,off (A) | 0.89 |  |  | Pg,loss (mW) | 40.38336
 |  |  |  | t_rise (ns) | 9.88 | Dmax (%) | 90 | Prg,mean (mW) | 31.23536906
 |  |  |  | t_fall (ns) | 7.55 | Rg,on+off (Ω) | 3.3 | Prgdint,mean (mW) | 9.147990936
 |  |  |  |  |  | Rg,eq,off | 2.5
 |  |  |  |  |  | Rg,mean (Ω) | 1.6

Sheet: CAL_Rshunt
 |  | Rshunt (µΩ) | 500 | Vref,adc (V) | 3.3
LIMITS |  | Iph typ (A) @ 95% ToF | 12.5 | Resolution (bit) | 12
Name | V1.0 | Vshunt,typ (mV) | 6.25 | OpAmp gain | 64
Iph typ (A) @ 95% ToF | 12.5 |  |  | Rshunt (µΩ) | 500
Iph max (A@Xs) @ 4.9% ToF | 20 |  |  | ΔIlsb (mA/bit) | 25.2
Iph mean (A) | 12.9
Iph spike (A@Xms) @ 0.1% ToF | 50 | Vshunt,typ (mV) | 6.25
Dmax (%) | 90 | OpAmp gain | 64
Rshunt |  | Vshunt,amp,typ (V) | 0.4
Rshunt (µΩ) | 500 |  |  | Rshunt (µΩ) | 500
ADC & OpAmp |  |  |  | Iph mean (A) | 12.905
Name | STM32G4 internal |  |  | Dmax (%) | 90
Resolution (bit) | 12 | Iph spike (A@Xms) @ 0.1% ToF | 50 | Pshunt,mean (mW) | 49.9617075
OpAmp gain | 64 | Rshunt (µΩ) | 500
Vref,adc (V) | 3.3 | Vshunt,spike (mV) | 25
 |  |  |  | Rshunt (µΩ) | 500
 |  | Vshunt,spike (mV) | 25 | Iph max (A@Xs) @ 4.9% ToF | 20
 |  | OpAmp gain | 64 | Dmax (%) | 90
 |  | Vshunt,amp,spike (V) | 1.6 | Pshunt,max (mW@Xs) | 120

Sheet: CAL_Rv1-2
 |  | Rv2 (Ω) | 1000 | Vbat,typ (V) | 25.20 | Rv1 (Ω) | 10000 | Csamp (pF) | 5
LIMITS |  | Vph spike (V) @ run | 35 | Rv1 (Ω) | 10000 | Rv2 (Ω) | 1000 | Cpad (pF) | 5
Name | V1.0 | Vref,adc (V) | 3.3 | Rv2 (Ω) | 1000 | Rthvn (Ω) | 909.0909091 | Ctrace,est (pF) | 5
Vph spike (V) @ run | 35 | Rv1,th (Ω) | 9606.060606 | Idivider,typ (mA) | 2.29 |  |  | Cadc,tot (pF) | 15.0
Vbat,typ (V) | 25.2 | Rv1 (Ω) | 10000
ADC & OpAmp
Name | STM32G4 internal
Vref,adc (V) | 3.3 |  |  |  |  |  |  | Charge factor (int) | 12
Resolution (bit) | 8 |  |  | Vdivider,spike (V) | 3.18 |  |  | Rthvn (Ω) | 909.0909091
Tadc,clock (ns) | 16.7 | Rv1 (Ω) | 10000 | Vdivider,typ (V) | 2.29 |  |  | Radc,ext (Ω) | 33
Nsamp (cycle) | 2.5 | Rv2 (Ω) | 1000 | Radc,ext (Ω) | 33 | Rthvn (Ω) | 909.0909091 | Cadc,tot (pF) | 15
Csamp (pF) | 5 | Vph spike (V) @ run | 35 | Imax-in,adc,spike (mA) | 96.41873278 | Radc,ext (Ω) | 33 | Tfill,samp (ns) | 169.6
Cpad (pF) | 5 | Prv1,rv2 (mW) | 111.3636364 | Imax-in,adc,typ (mA) | 69.4214876 | Cadc,ext (pF) | 100
Ctrace,est (pF) | 5 |  |  |  |  | Fc,adc,ext (MHz) | 1.7
Rv2 & Rtrace
Rv2 name | 1kΩ, 1005m
Rv2 (Ω) | 1000
Radc,ext name | 33Ω, 1005m | Rv1 (Ω) | 10000
Radc,ext (Ω) | 33 | Rv2 (Ω) | 1000 |  |  | Cadc,ext (pF) | 100
Cadc,ext |  | Vph spike (V) @ run | 35 | Vdivider,spike (V) | 3.18 | Expected derating (%) | 40
Cadc,ext (pF) | 100 | Vbat,typ (V) | 25.2 | Vref,adc (V) | 3.3 | Cadc,ext,real (pF) | 60
Expected derating (%) | 40 | Vdivider,spike (V) | 3.18 | Resolution (bit) | 8
Charge factor (int) | 12 | Vdivider,typ (V) | 2.29 | Vph spike (V) @ run | 35
Charge factor (ext) | 5 |  |  | ΔVlsb,fullscale (mV/bit) | 142.4
 |  |  |  |  |  | Charge factor (ext) | 5
 |  |  |  |  |  | Rthvn (Ω) | 909.0909091
 |  |  |  |  |  | Radc,ext (Ω) | 33
 |  |  |  |  |  | Cadc,ext,real (pF) | 60
 |  |  |  |  |  | Tfill,adc,ext (ns) | 282.6

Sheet: CAL_Vbat
 |  | R1 (Ω) | 22000
LIMITS |  | R2 (Ω) | 1000
Name | V1.0 | Vbat spike (V) @ disarm | 45
Vbat spike (V) @ disarm | 45 | Vbat,adc,max (V) | 1.96
Vbat,typ (V) | 25.2
VBAT Sensing
R1 name | 22kΩ, 1005m
R1 (Ω) | 22000
R2 name | 1kΩ, 1005m | R1 (Ω) | 22000
R2 (Ω) | 1000 | R2 (Ω) | 1000
 |  | Vbat,typ (V) | 25.2
 |  | Vbat,adc,typ (V) | 1.10
 |  | R1 (Ω) | 22000
 |  | R2 (Ω) | 1000
 |  | Rbat,adc,thev (Ω) | 956.52

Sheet: DB_LIMITS
Name | Frame size (") | Dmax (%) | Fmax (kHz) | Fmin (kHz) | Batt max (S) | Batt min (S) | Cell max (V) | Cell typ (V) | Cell min (V) | Vbat,typ (V) | Vbat,min (V) | Vbat spike (V) @ run | Vph spike (V) @ run | Vbat spike (V) @ disarm | Vph spike (V) @ disarm | Iph typ (A) | ToF Iph typ (%) | Iph max (A@Xs) | ToF Iph max (%) | Iph spike (A@Xms) | ToF Iph spike (%) | Iph mean (A) | Termistors
V1.0 | 6 | 90 | 64 | 24 | 6 | 4 | 4.2 | 3.7 | 3.5 | 25.2 | 14 | 32 | 35 | 45 | 28 | 12.5 | 95 | 20 | 4.9 | 50 | 0.1 | 12.905 | 1 (at a FET)
V1.0 (48kHz) | 6 | 90 | 48 | 24 | 6 | 4 | 4.2 | 3.7 | 3.5 | 25.2 | 14 | 32 | 35 | 45 | 28 | 12.5 | 95 | 20 | 4.9 | 50 | 0.1 | 12.905 | 1 (at a FET)
V1.0 (hard flight) | 6 | 90 | 64 | 24 | 6 | 4 | 4.2 | 3.7 | 3.5 | 25.2 | 14 | 32 | 35 | 45 | 28 | 12.5 | 85 | 25 | 14 | 50 | 1 | 14.625 | 1 (at a FET)
V1.0 (95%D) | 6 | 95 | 64 | 24 | 6 | 4 | 4.2 | 3.7 | 3.5 | 25.2 | 14 | 32 | 35 | 45 | 28 | 12.5 | 95 | 20 | 4.9 | 50 | 0.1 | 12.905 | 1 (at a FET)
V2.0 | 6 | 95 | 96 | 24 | 6 | 4 | 4.2 | 3.7 | 3.25 | 25.2 | 13 | 32 | 35 | 45 | 28 | 15 | 85 | 25 | 14 | 60 | 1 | 16.85 | 1 (at a FET)
V1.0 (48kHz + hard flight) | 6 | 90 | 64 | 24 | 6 | 4 | 4.2 | 3.7 | 3.5 | 25.2 | 14 | 32 | 35 | 45 | 28 | 12.5 | 85 | 25 | 14 | 50 | 1 | 14.625 | 1 (at a FET)

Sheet: DB_GD
Part | Vhbr (V) | Vhbh,max (V) | Rboot,int (Ω) | Ihb (mA) | Ihbs (mA) | Vout (V) | Rpu,hs (Ω) | Rpu,ls (Ω) | Rpd,hs (Ω) | Rpd,ls (Ω) | Vfint,100mA (V)
Infineon 2EDL8024 | 6 | 0.5 | 21.5 | 0.7 | 1.25 | 10 | 1 | 1 | 0.5 | 0.35 | 2.15

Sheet: DB_R
Description | R (Ω) | R (kΩ) | Prated@70°C (mW) | Package (inch) | Package (m) | Name | Basic
10Ω, 1005m | 10 | 0.01 | 65 | 0402 | 1005m |  | UKN
11Ω, 1005m | 11 | 0.011 | 65 | 0402 | 1005m |  | UKN
12Ω, 1005m | 12 | 0.012 | 65 | 0402 | 1005m |  | UKN
13Ω, 1005m | 13 | 0.013 | 65 | 0402 | 1005m |  | UKN
15Ω, 1005m | 15 | 0.015 | 65 | 0402 | 1005m |  | UKN
16Ω, 1005m | 16 | 0.016 | 65 | 0402 | 1005m |  | UKN
18Ω, 1005m | 18 | 0.018 | 65 | 0402 | 1005m |  | UKN
20Ω, 1005m | 20 | 0.02 | 65 | 0402 | 1005m |  | UKN
22Ω, 1005m | 22 | 0.022 | 65 | 0402 | 1005m |  | UKN
24Ω, 1005m | 24 | 0.024 | 65 | 0402 | 1005m |  | UKN
27Ω, 1005m | 27 | 0.027 | 65 | 0402 | 1005m |  | UKN
30Ω, 1005m | 30 | 0.03 | 65 | 0402 | 1005m |  | UKN
33Ω, 1005m | 33 | 0.033 | 65 | 0402 | 1005m |  | UKN
47Ω, 1005m | 47 | 0.047 | 65 | 0402 | 1005m |  | UKN
51Ω, 1005m | 51 | 0.051 | 65 | 0402 | 1005m |  | UKN
56Ω, 1005m | 56 | 0.056 | 65 | 0402 | 1005m |  | UKN
62Ω, 1005m | 62 | 0.062 | 65 | 0402 | 1005m |  | UKN
68Ω, 1005m | 68 | 0.068 | 65 | 0402 | 1005m |  | UKN
75Ω, 1005m | 75 | 0.075 | 65 | 0402 | 1005m |  | UKN
82Ω, 1005m | 82 | 0.082 | 65 | 0402 | 1005m |  | UKN
91Ω, 1005m | 91 | 0.091 | 65 | 0402 | 1005m |  | UKN
100Ω, 1005m | 100 | 0.1 | 65 | 0402 | 1005m |  | UKN
110Ω, 1005m | 110 | 0.11 | 65 | 0402 | 1005m |  | UKN
120Ω, 1005m | 120 | 0.12 | 65 | 0402 | 1005m |  | UKN
130Ω, 1005m | 130 | 0.13 | 65 | 0402 | 1005m |  | UKN
150Ω, 1005m | 150 | 0.15 | 65 | 0402 | 1005m |  | UKN
160Ω, 1005m | 160 | 0.16 | 65 | 0402 | 1005m |  | UKN
180Ω, 1005m | 180 | 0.18 | 65 | 0402 | 1005m |  | UKN
200Ω, 1005m | 200 | 0.2 | 65 | 0402 | 1005m |  | UKN
220Ω, 1005m | 220 | 0.22 | 65 | 0402 | 1005m |  | UKN
240Ω, 1005m | 240 | 0.24 | 65 | 0402 | 1005m |  | UKN
270Ω, 1005m | 270 | 0.27 | 65 | 0402 | 1005m |  | UKN
300Ω, 1005m | 300 | 0.3 | 65 | 0402 | 1005m |  | UKN
330Ω, 1005m | 330 | 0.33 | 65 | 0402 | 1005m |  | UKN
360Ω, 1005m | 360 | 0.36 | 65 | 0402 | 1005m |  | UKN
390Ω, 1005m | 390 | 0.39 | 65 | 0402 | 1005m |  | UKN
430Ω, 1005m | 430 | 0.43 | 65 | 0402 | 1005m |  | UKN
470Ω, 1005m | 470 | 0.47 | 65 | 0402 | 1005m |  | UKN
510Ω, 1005m | 510 | 0.51 | 65 | 0402 | 1005m |  | UKN
560Ω, 1005m | 560 | 0.56 | 65 | 0402 | 1005m |  | UKN
620Ω, 1005m | 620 | 0.62 | 65 | 0402 | 1005m |  | UKN
680Ω, 1005m | 680 | 0.68 | 65 | 0402 | 1005m |  | UKN
750Ω, 1005m | 750 | 0.75 | 65 | 0402 | 1005m |  | UKN
820Ω, 1005m | 820 | 0.82 | 65 | 0402 | 1005m |  | UKN
910Ω, 1005m | 910 | 0.91 | 65 | 0402 | 1005m |  | UKN
1kΩ, 1005m | 1000 | 1 | 65 | 0402 | 1005m |  | UKN
1.1kΩ, 1005m | 1100 | 1.1 | 65 | 0402 | 1005m |  | UKN
1.2kΩ, 1005m | 1200 | 1.2 | 65 | 0402 | 1005m |  | UKN
1.3kΩ, 1005m | 1300 | 1.3 | 65 | 0402 | 1005m |  | UKN
1.5kΩ, 1005m | 1500 | 1.5 | 65 | 0402 | 1005m |  | UKN
1.6kΩ, 1005m | 1600 | 1.6 | 65 | 0402 | 1005m |  | UKN
1.8kΩ, 1005m | 1800 | 1.8 | 65 | 0402 | 1005m |  | UKN
2kΩ, 1005m | 2000 | 2 | 65 | 0402 | 1005m |  | UKN
2.2kΩ, 1005m | 2200 | 2.2 | 65 | 0402 | 1005m |  | UKN
2.4kΩ, 1005m | 2400 | 2.4 | 65 | 0402 | 1005m |  | UKN
2.7kΩ, 1005m | 2700 | 2.7 | 65 | 0402 | 1005m |  | UKN
3kΩ, 1005m | 3000 | 3 | 65 | 0402 | 1005m |  | UKN
3kΩ, 1005m | 3000 | 3 | 65 | 0402 | 1005m |  | UKN
3.3kΩ, 1005m | 3300 | 3.3 | 65 | 0402 | 1005m |  | UKN
3.6kΩ, 1005m | 3600 | 3.6 | 65 | 0402 | 1005m |  | UKN
3.9kΩ, 1005m | 3900 | 3.9 | 65 | 0402 | 1005m |  | UKN
4.3kΩ, 1005m | 4300 | 4.3 | 65 | 0402 | 1005m |  | UKN
4.7kΩ, 1005m | 4700 | 4.7 | 65 | 0402 | 1005m |  | UKN
5.1kΩ, 1005m | 5100 | 5.1 | 65 | 0402 | 1005m |  | UKN
5.6kΩ, 1005m | 5600 | 5.6 | 65 | 0402 | 1005m |  | UKN
6.2kΩ, 1005m | 6200 | 6.2 | 65 | 0402 | 1005m |  | UKN
6.8kΩ, 1005m | 6800 | 6.8 | 65 | 0402 | 1005m |  | UKN
7.5kΩ, 1005m | 7500 | 7.5 | 65 | 0402 | 1005m |  | UKN
8.2kΩ, 1005m | 8200 | 8.2 | 65 | 0402 | 1005m |  | UKN
9.1kΩ, 1005m | 9100 | 9.1 | 65 | 0402 | 1005m |  | UKN
10kΩ, 1005m | 10000 | 10 | 65 | 0402 | 1005m |  | Yes
10kΩ, 1005m | 10000 | 10 | 65 | 0402 | 1005m |  | Yes
11kΩ, 1005m | 11000 | 11 | 65 | 0402 | 1005m |  | Yes
12kΩ, 1005m | 12000 | 12 | 65 | 0402 | 1005m |  | Yes
13kΩ, 1005m | 13000 | 13 | 65 | 0402 | 1005m |  | Yes
15kΩ, 1005m | 15000 | 15 | 65 | 0402 | 1005m |  | Yes
16kΩ, 1005m | 16000 | 16 | 65 | 0402 | 1005m |  | Yes
18kΩ, 1005m | 18000 | 18 | 65 | 0402 | 1005m |  | Yes
20kΩ, 1005m | 20000 | 20 | 65 | 0402 | 1005m |  | Yes
22kΩ, 1005m | 22000 | 22 | 65 | 0402 | 1005m |  | Yes
24kΩ, | 24000 | 24
27kΩ, | 27000 | 27
30kΩ, | 30000 | 30
33kΩ, | 33000 | 33
36kΩ, | 36000 | 36
39kΩ, | 39000 | 39
43kΩ, | 43000 | 43
47kΩ, | 47000 | 47
51kΩ, | 51000 | 51
56kΩ, | 56000 | 56
62kΩ, | 62000 | 62
68kΩ, | 68000 | 68
75kΩ, | 75000 | 75
82kΩ, | 82000 | 82
91kΩ, | 91000 | 91
100kΩ, | 100000 | 100

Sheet: DB_D
Ref | Vf@100mA (V)
Rohm RB161QS-40 | 0.24

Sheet: DB_FETS
Part | Manifacturer | Vds (V) | Rds,on@10V typ(mΩ) | Rds,on@10V max (mΩ) | Qg,typ @ 10V (nC) | Qg,max @ 10V (nC) | Qg,typ,sync @ 10V (nC) | Id @ Tc=25°C (A) | Id @ Tc>70°C (A) | Id @ Ta=25°C (A) | Id @ Ta>70°C (A) | Id,pulsed (A) | Rise time (ns) | Fall time (ns) | Size (mm) | Vmiller (V) | Qgd,typ (nC) | Rg,int,max (Ω) | JLCPBC stock
STL180N6F7 | STM | 60 | 1.9 | 2.4 | 79.5 | X | X | 120 | 120 | 32 | 20 | 128 | 35.6 | 42.2 | 5x6 |  |  |  | No
NVMFS5C604NL | Onsemi | 60 | 0.93 | 1.2 | 120 | X | X | 287 | 200 | 40 | 28 | 900 | 79.1 | 81.3 | 5x6 |  |  |  | Yes
TPN4R806PL | Toshiba | 60 | 3.5 | 4.8 | 29 | X | X | 72 | 105 | (est ~15) | (est <15) | 200 | 4 | 5.1 | 3.3x3.3 |  |  |  | No
SiR186LDP | Vishay | 60 | 3.5 | 4.4 | 31.5 | X | X | 80.3 | 64.2 | 23.8 | 19 | 150 | 6 | 6 | 5x6 |  |  |  | Yes
BSC027N06LS5 | Infineon | 60 | 2.3 | 2.7 | 43 | X | X | 134 | 84 | 23 | (est ~13-15A) | 536 | 4.8 | 5.4 | 5x6 |  |  |  | ~Yes
BSC016N06NS | Infineon | 60 | 1.4 | 1.6 | 71 | 95 | 62 | 234 | 164 | 31 | (est ~21A) | 936 | 9 | 9 | 5x6 |  |  |  | Yes
TI CSD18540Q5B | TI | 60 | 1.8 | 2.2 | 41 | 53 | X | 100 | 100 | 29 | (est ~21A) | 400 | 9 | 3 | 5x6 | 4 | 6.7 | 1.6 | Yes
 |  |  |  |  |  |  |  |  |  |  |  |  | Depend of Rg | Depend of Rg

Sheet: DB_ADC
Name | Vref,adc (V) | Vmax (V) | Csamp (pF) | Cpad (pF) | Fadc,clock(MHz) | Tadc,clock (ns) | Vin,max@vin (V)
STM32G4 internal | 3.3 | 3.6 | 5 | 5 | 60 | 16.7 | 3.6

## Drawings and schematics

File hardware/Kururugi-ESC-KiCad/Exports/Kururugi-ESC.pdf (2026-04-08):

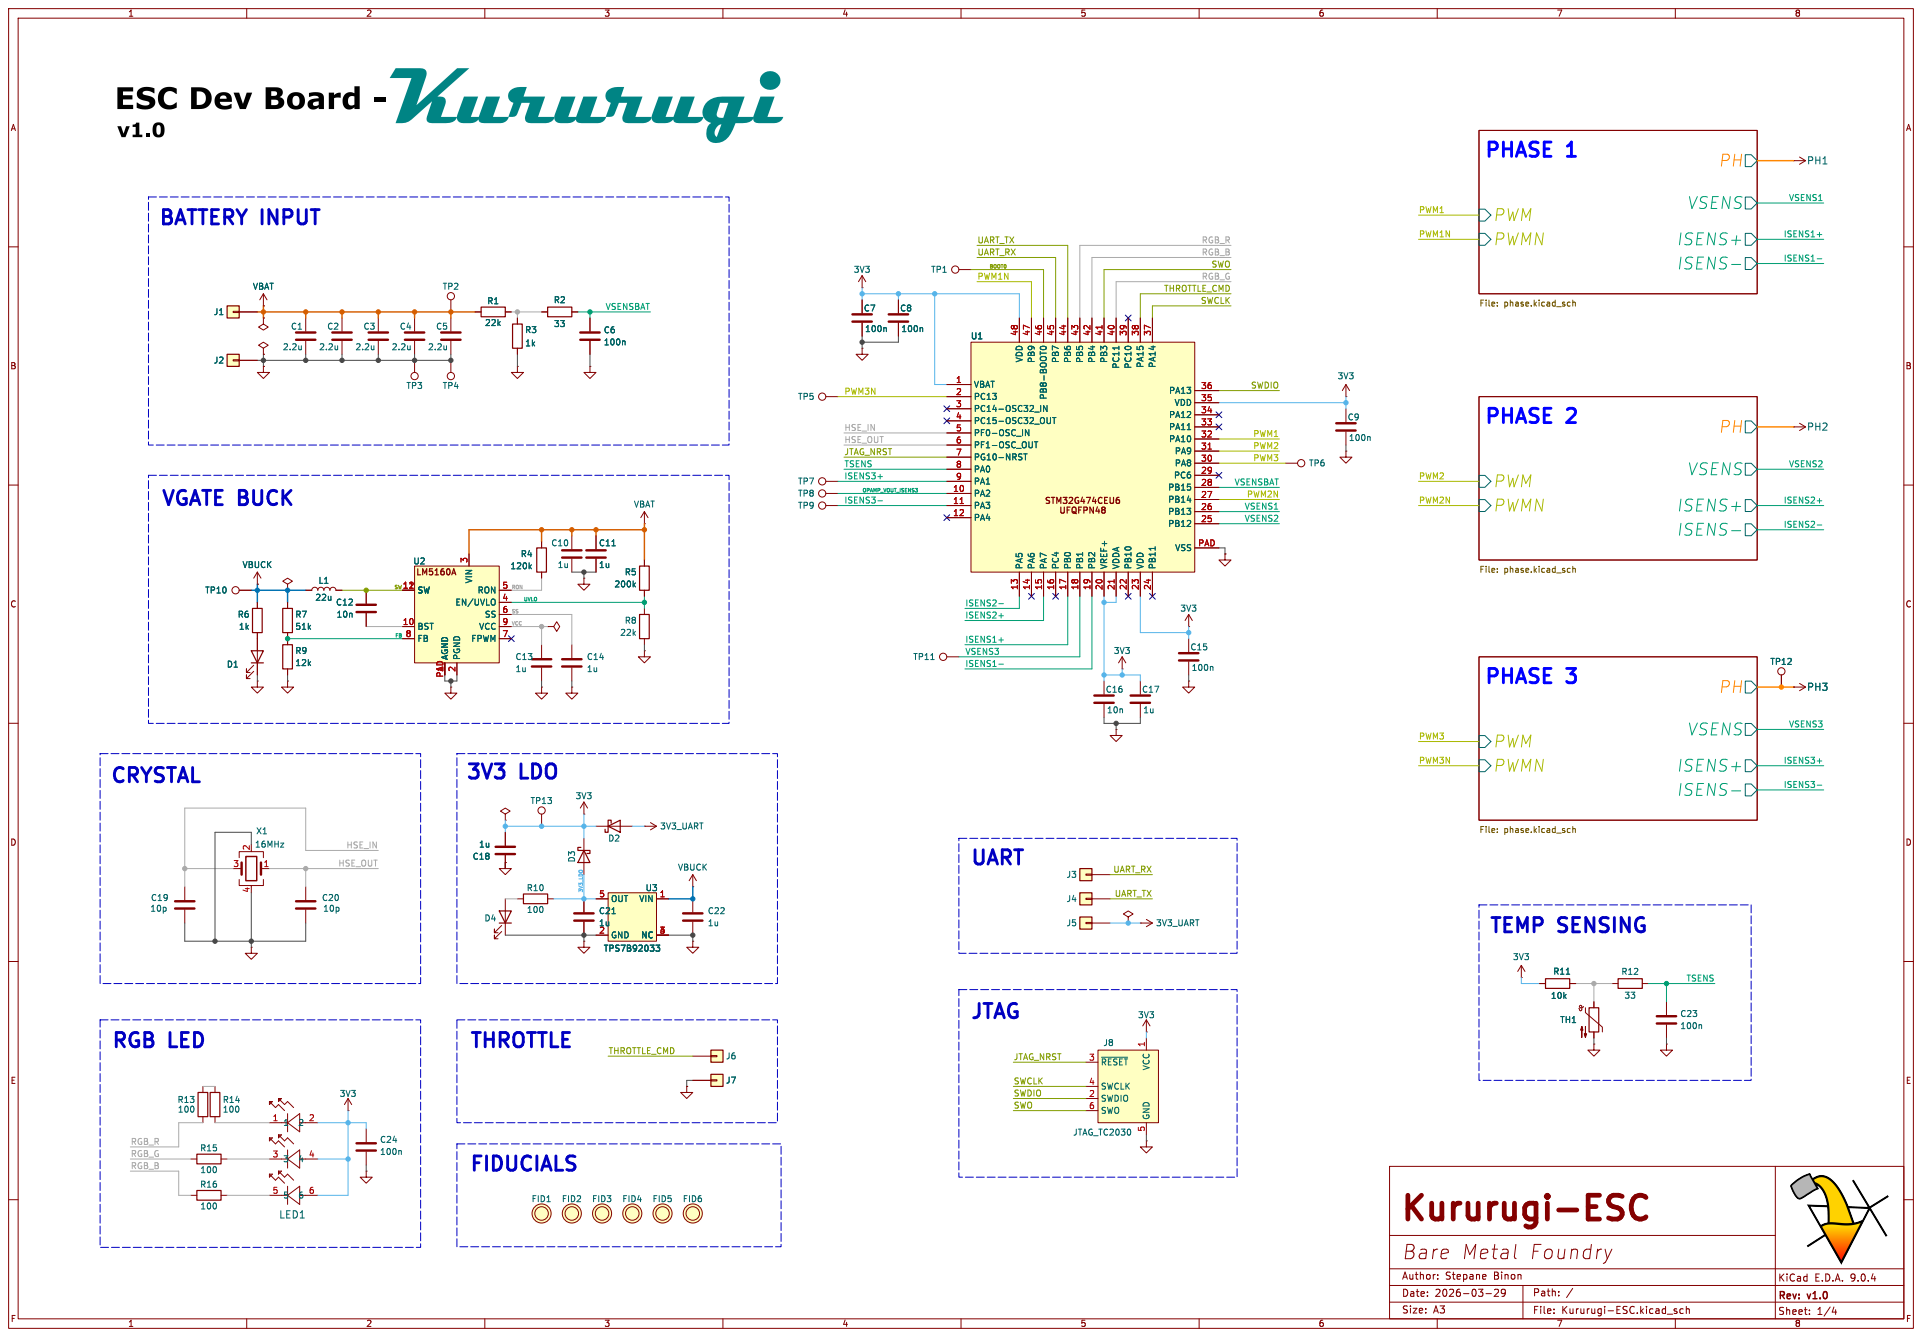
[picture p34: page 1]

Kururugi
HSE_OUT ESC Dev Board - BATTERY INPUT

3 PGND
RON 5 EN/UVLO 4 SS 6 VCC 9 FPWM 7 VIN

TP12 U3 TPS7B92033 VIN 1 NC 34 OUT 5 GND 2C21

5 ~{RESET} 3 SWCLK 4 SWDIO 2 SWO 6

File: Kururugi-ESC.kicad_sch Path: / Bare Metal Foundry

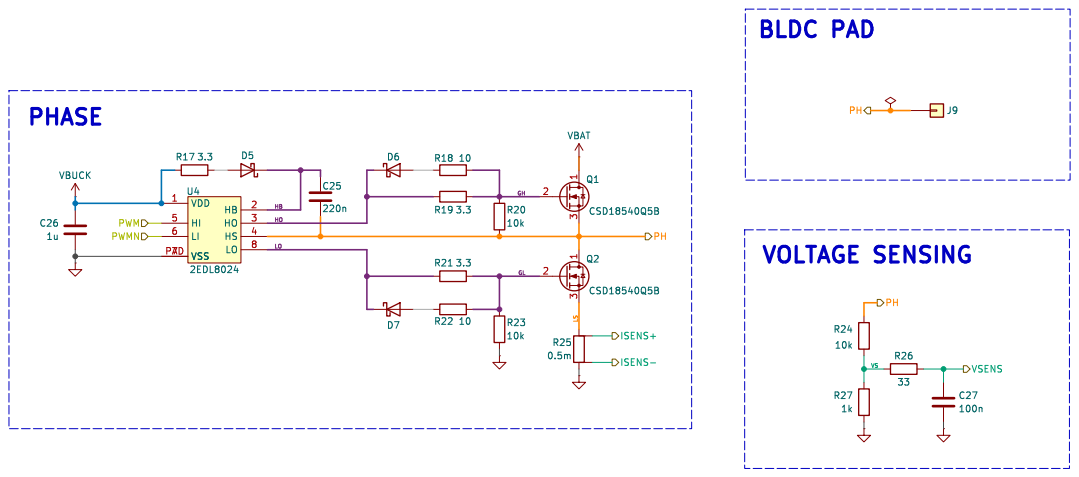
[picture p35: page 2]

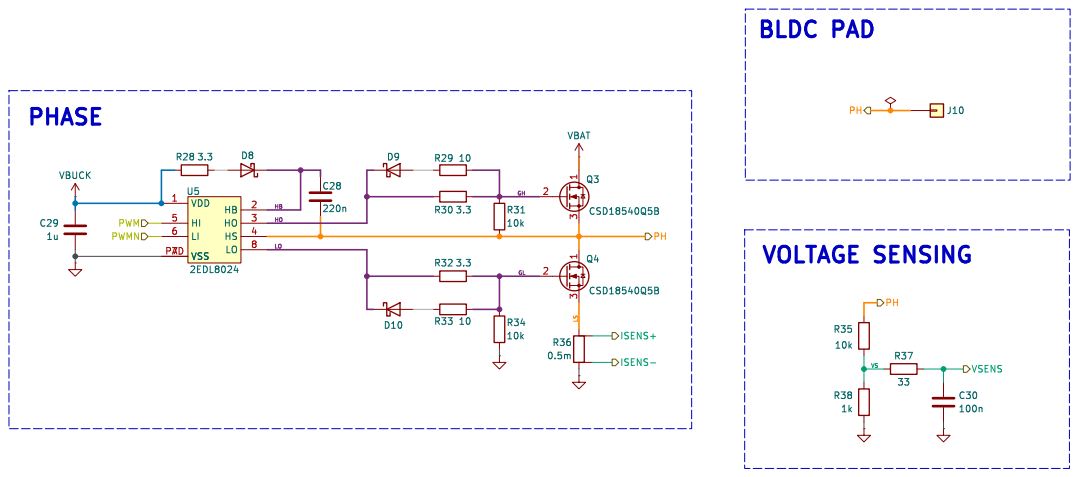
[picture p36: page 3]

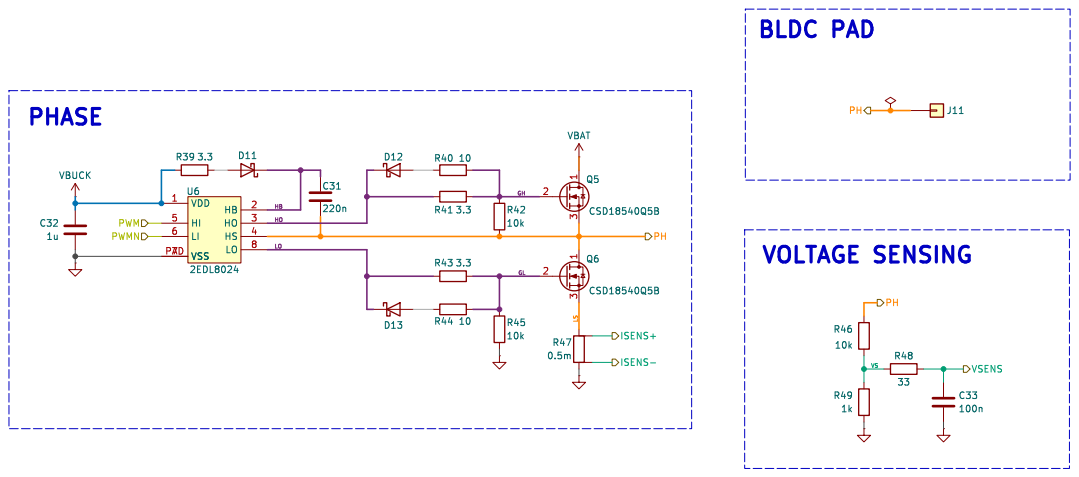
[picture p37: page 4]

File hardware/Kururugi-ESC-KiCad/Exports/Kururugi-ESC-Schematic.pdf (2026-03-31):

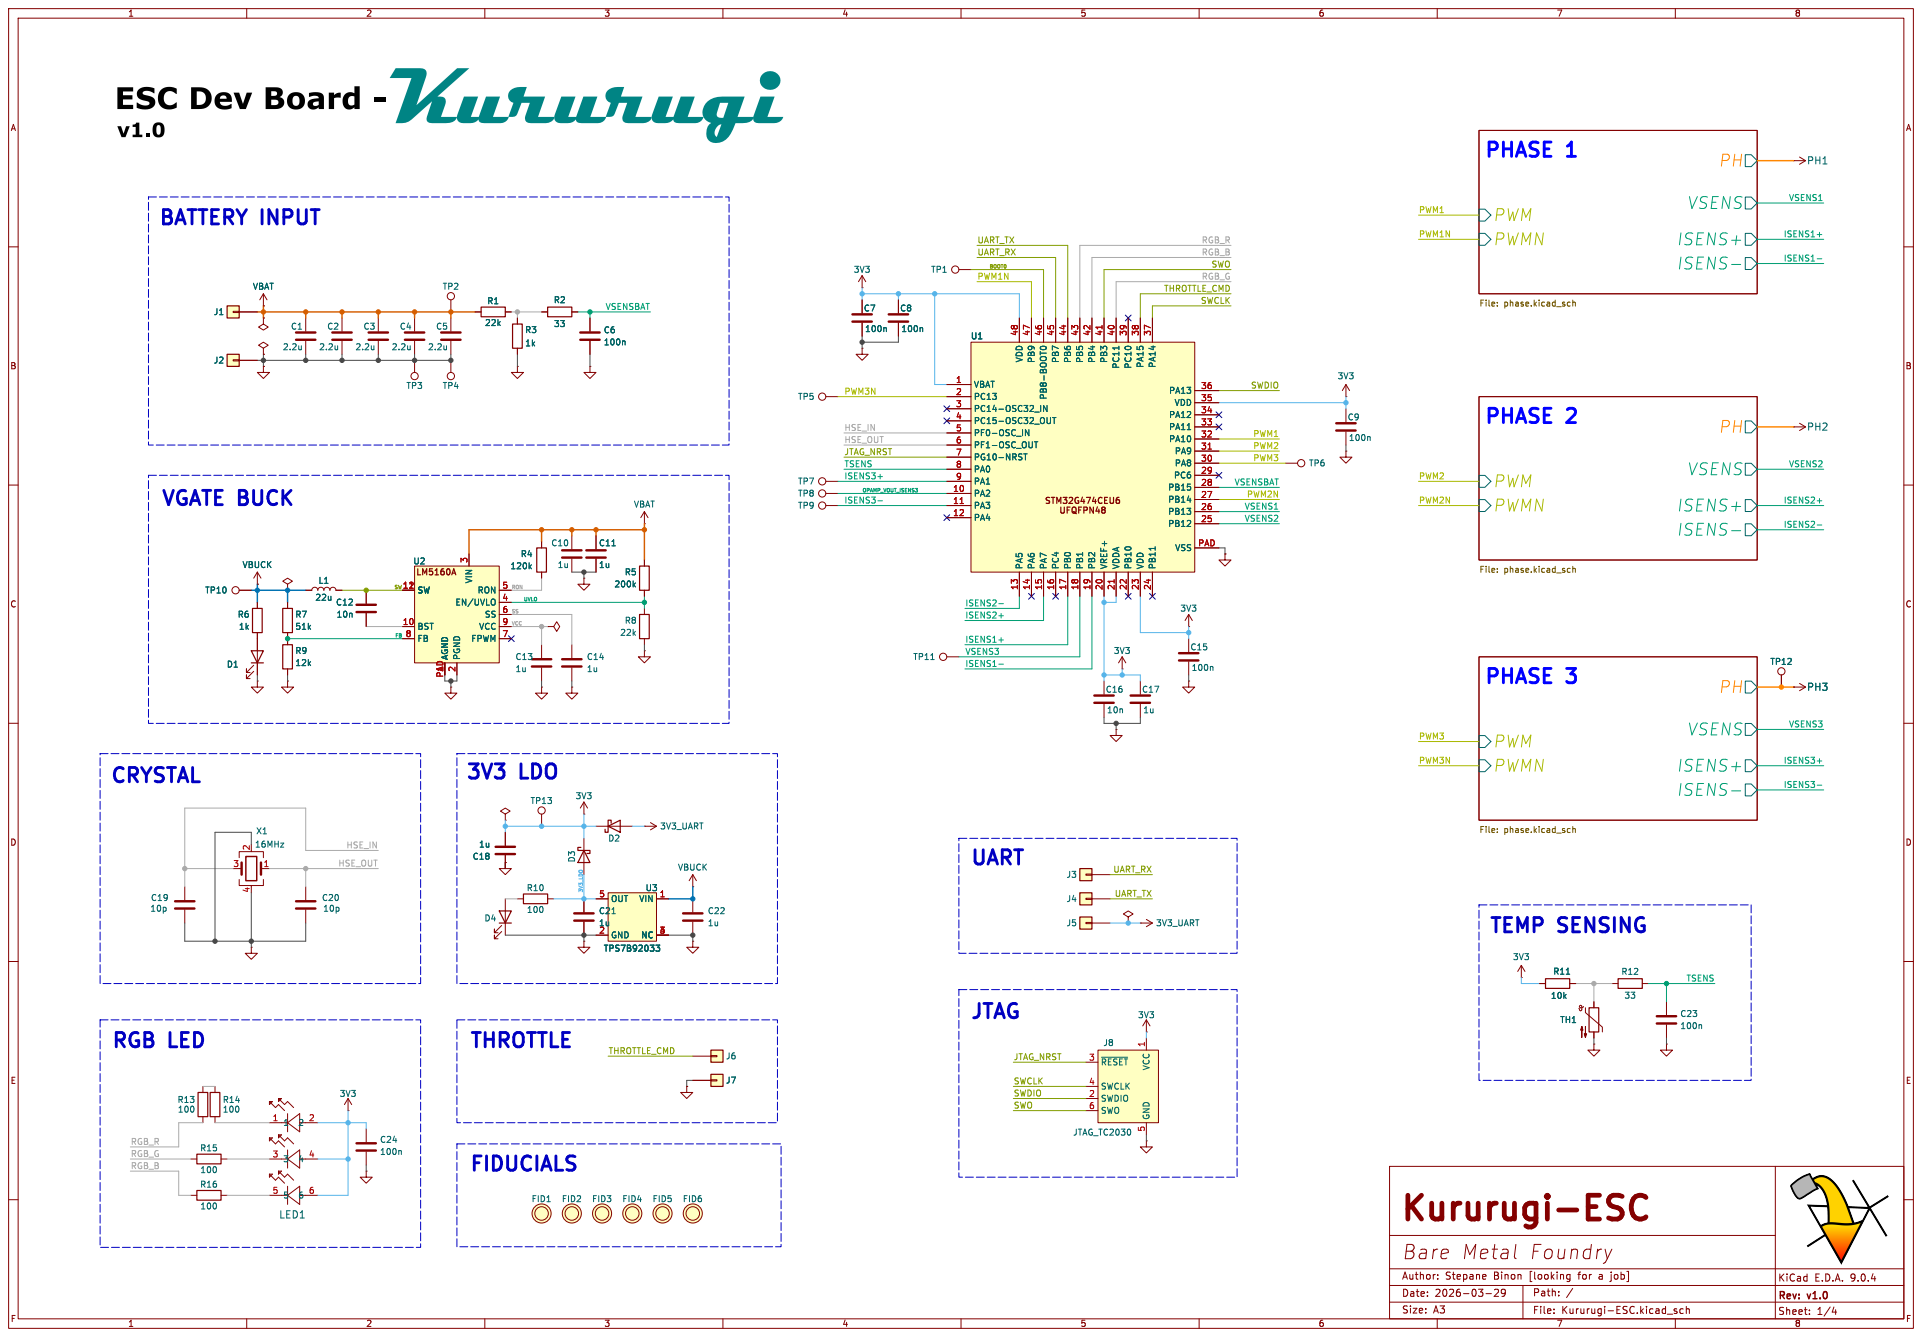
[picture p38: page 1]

3 PGND
RON 5 EN/UVLO 4 SS 6 VCC 9 FPWM 7 VIN

5 ~{RESET} 3 SWCLK 4 SWDIO 2 SWO 6

File: Kururugi-ESC.kicad_sch Path: / Bare Metal Foundry

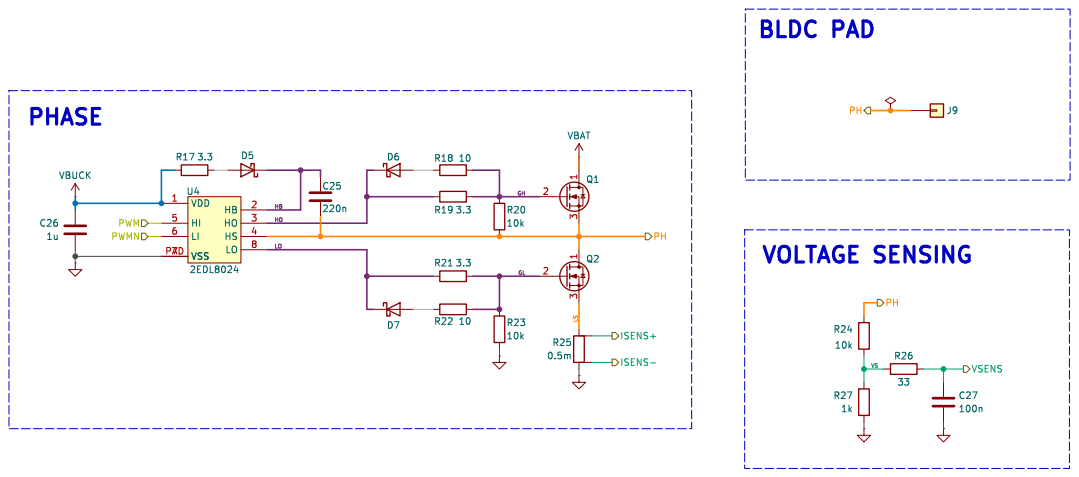
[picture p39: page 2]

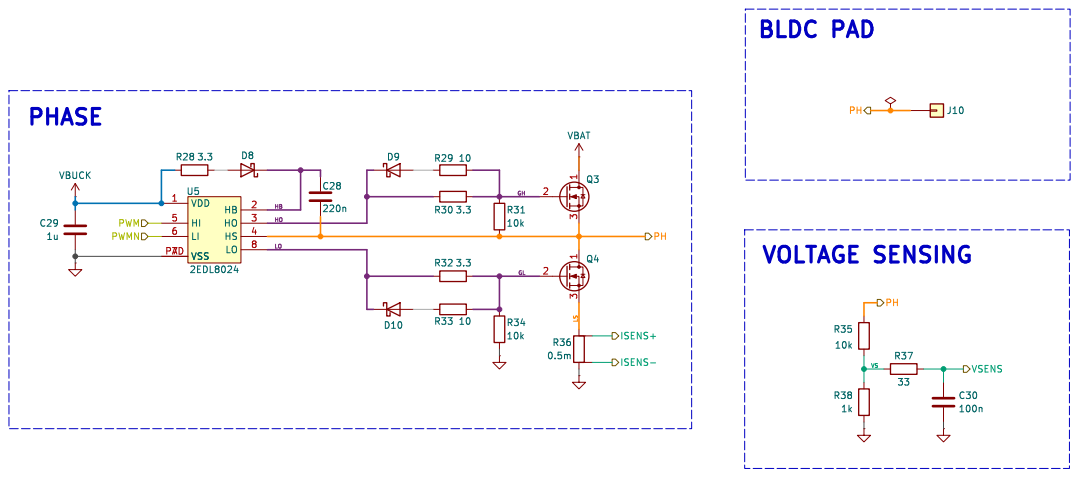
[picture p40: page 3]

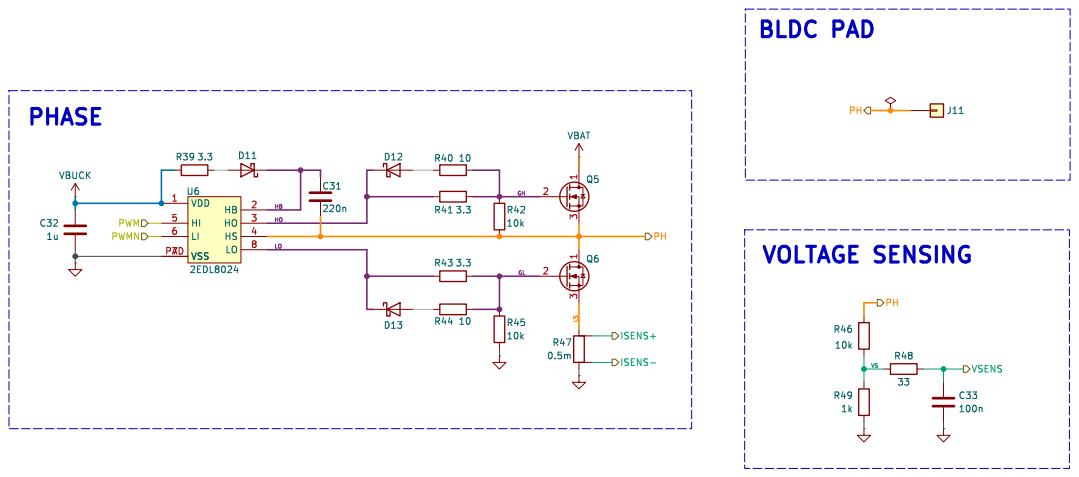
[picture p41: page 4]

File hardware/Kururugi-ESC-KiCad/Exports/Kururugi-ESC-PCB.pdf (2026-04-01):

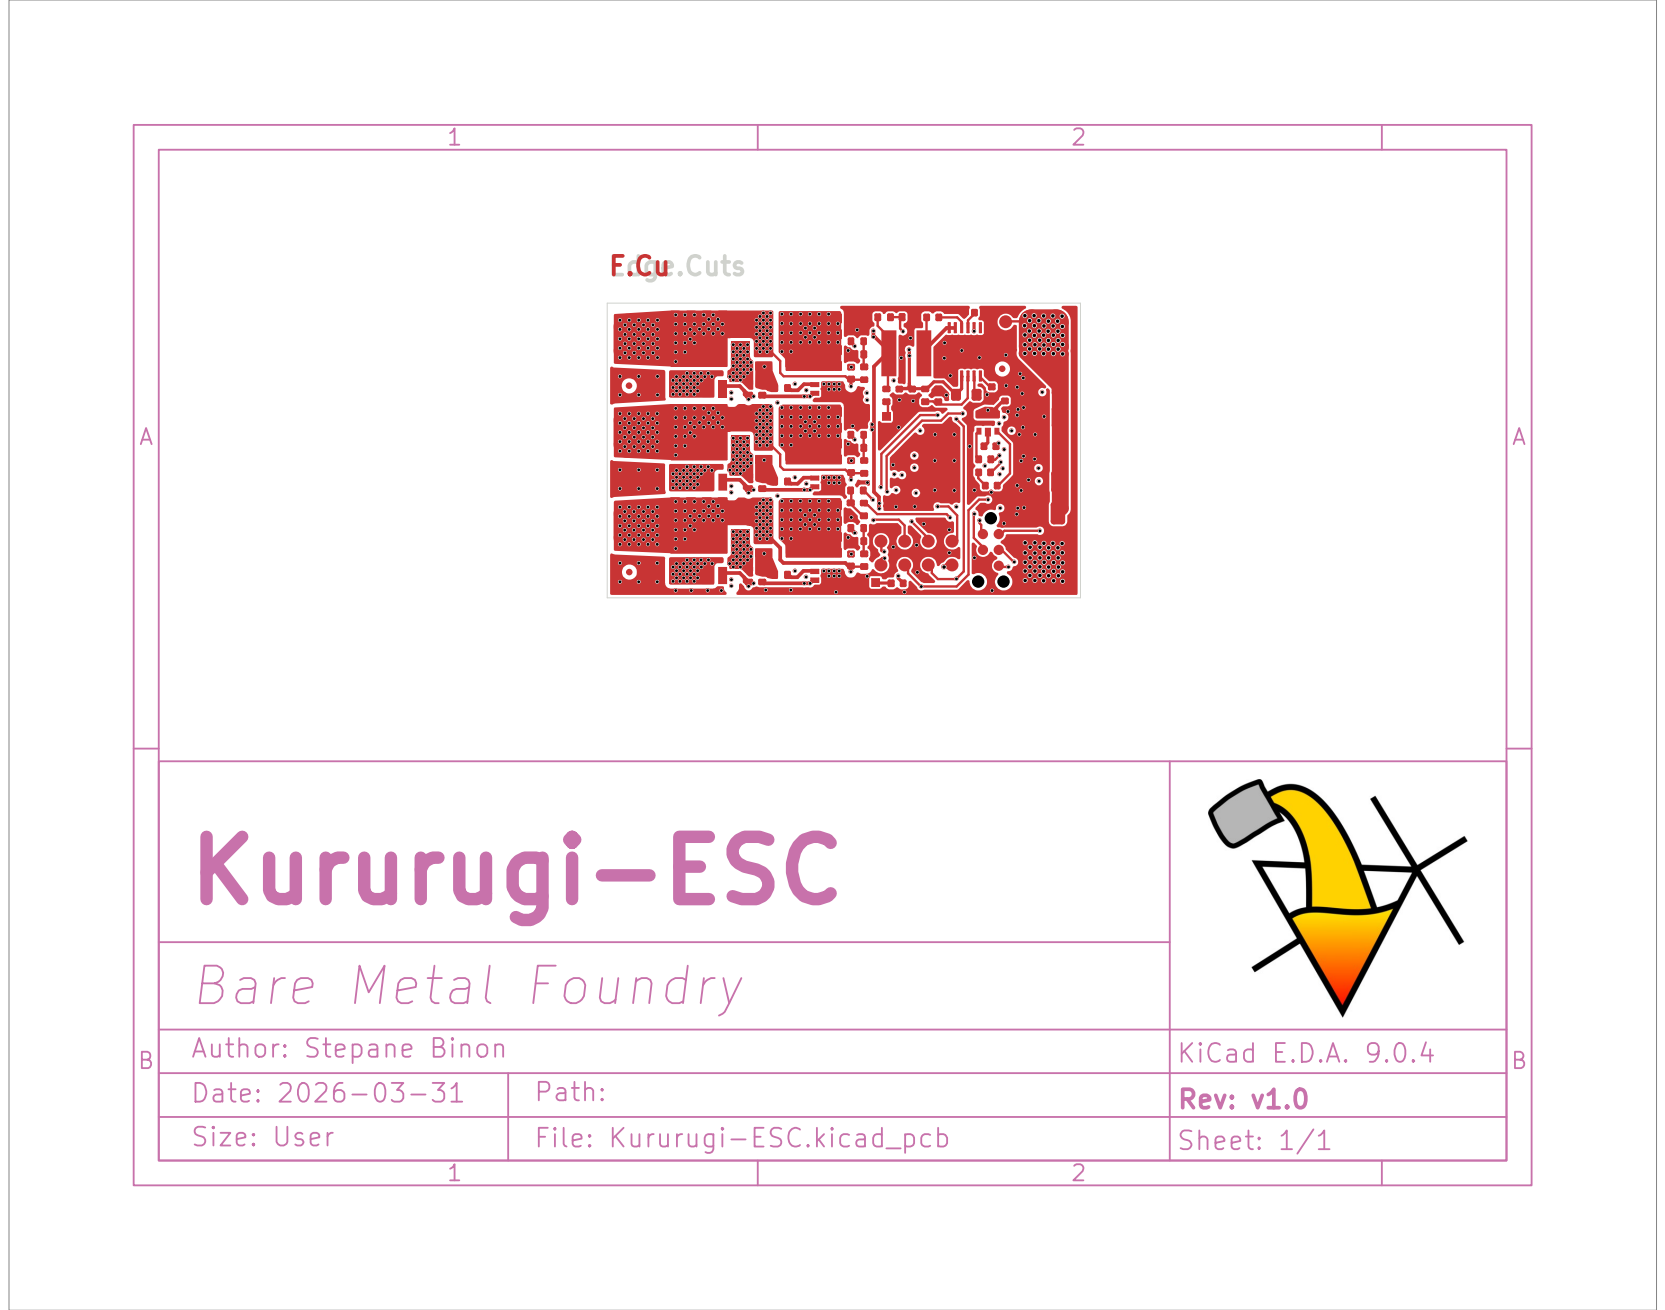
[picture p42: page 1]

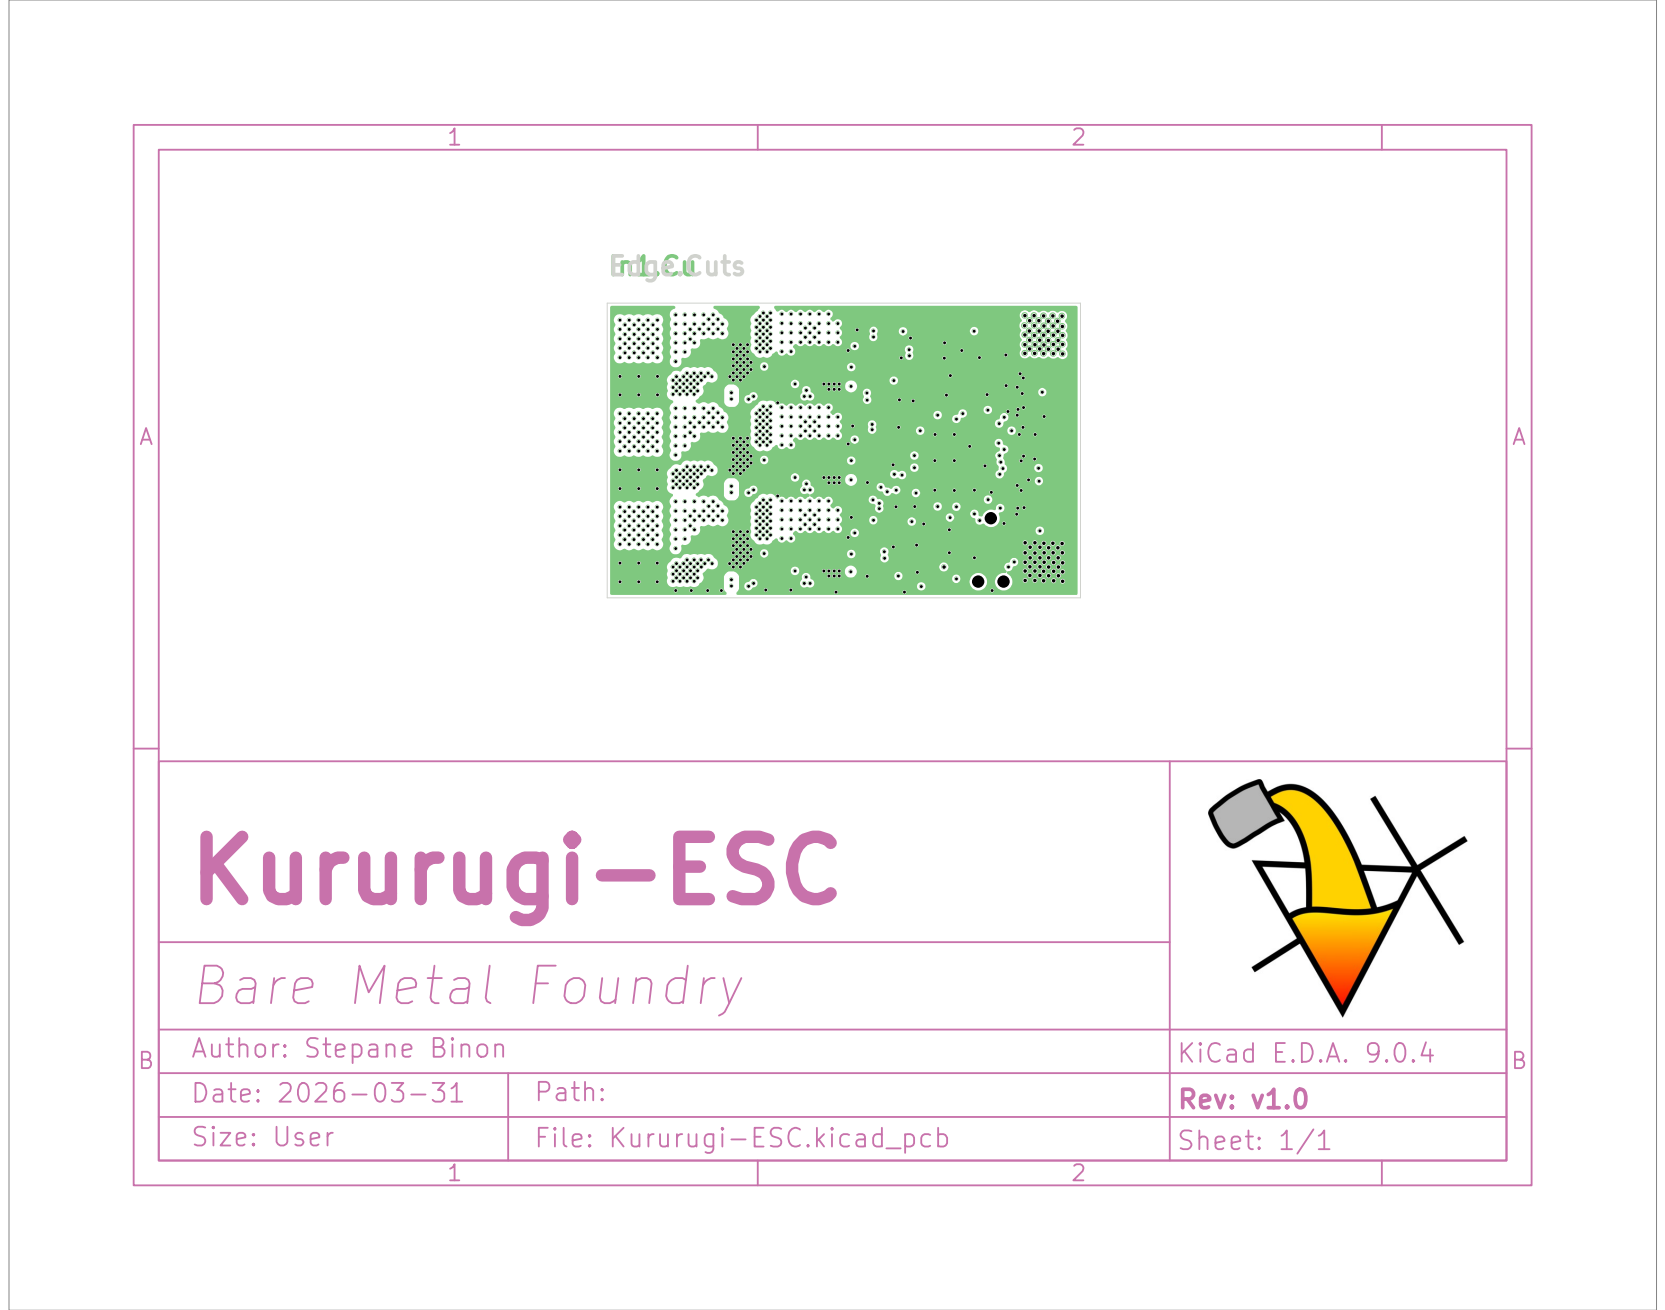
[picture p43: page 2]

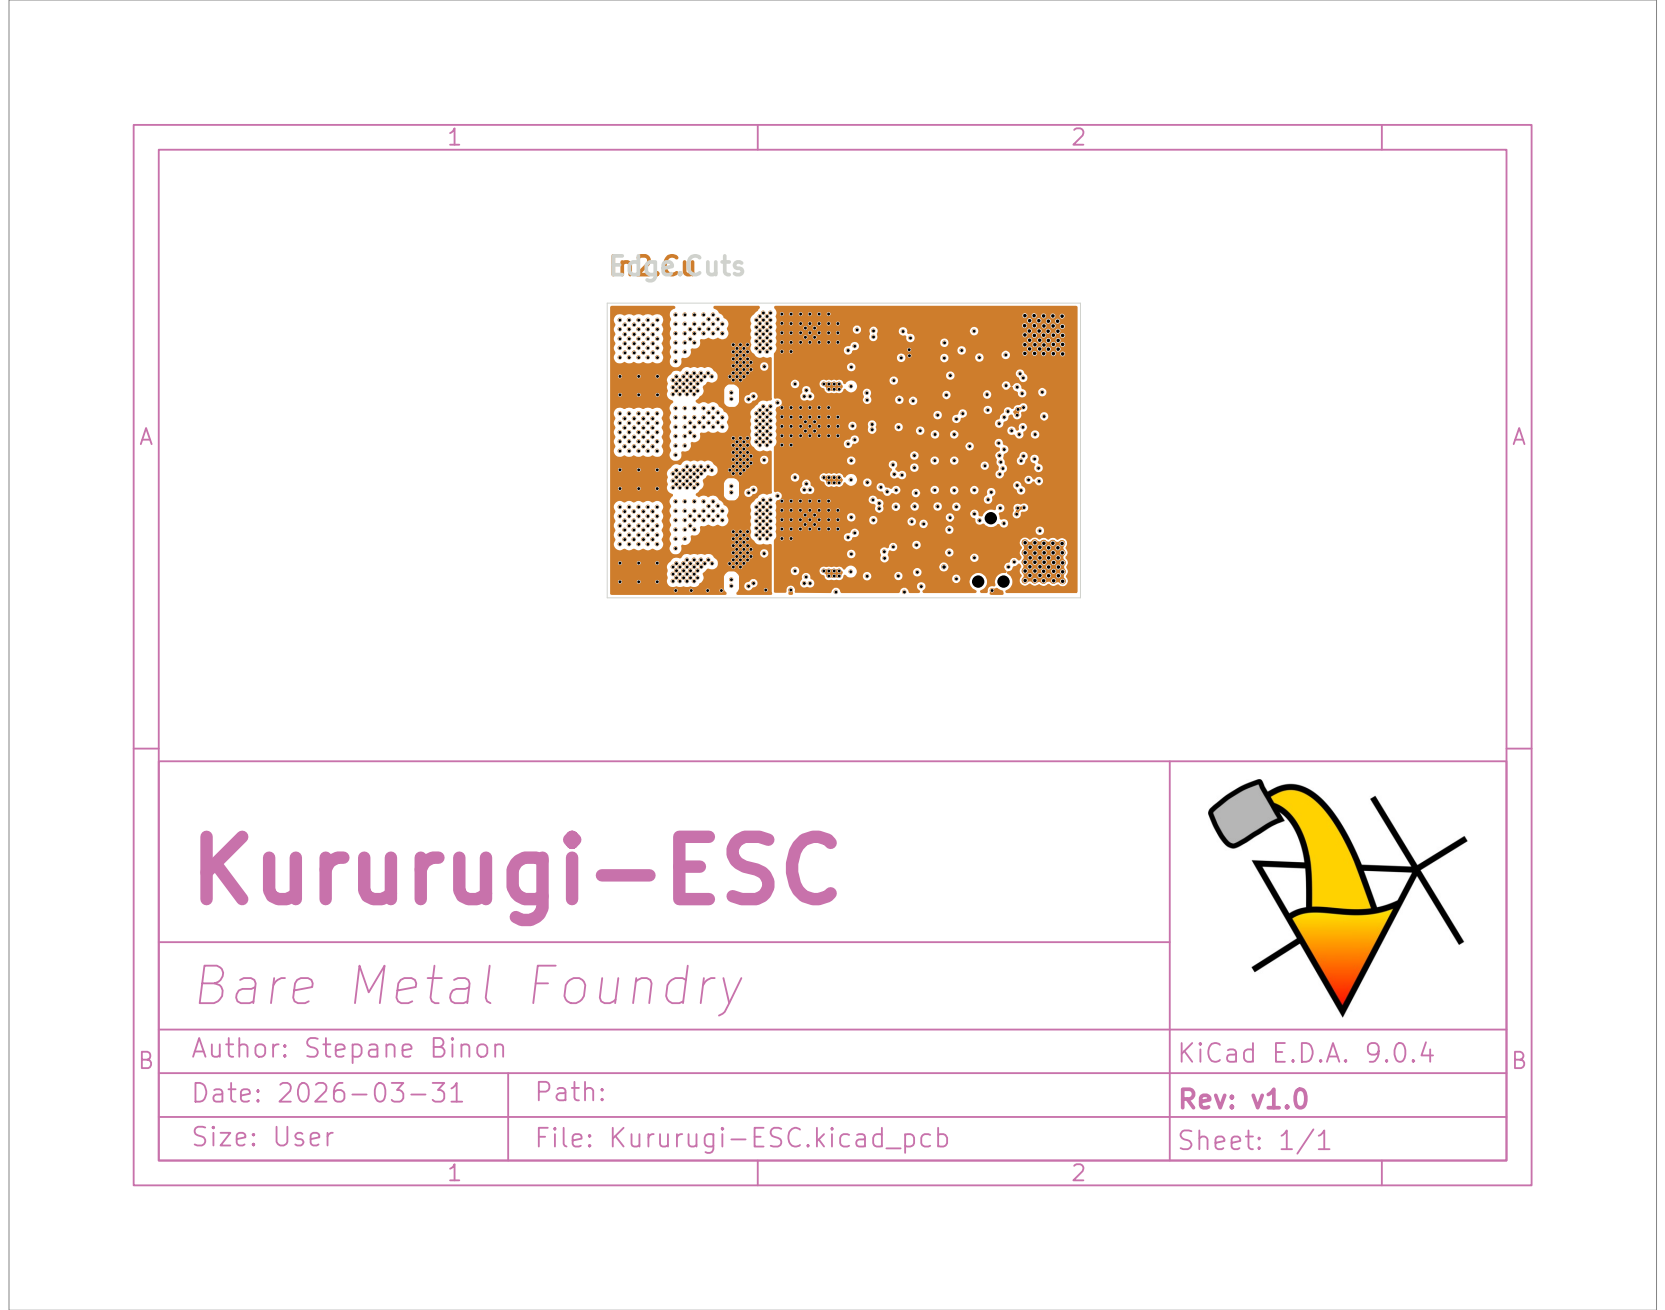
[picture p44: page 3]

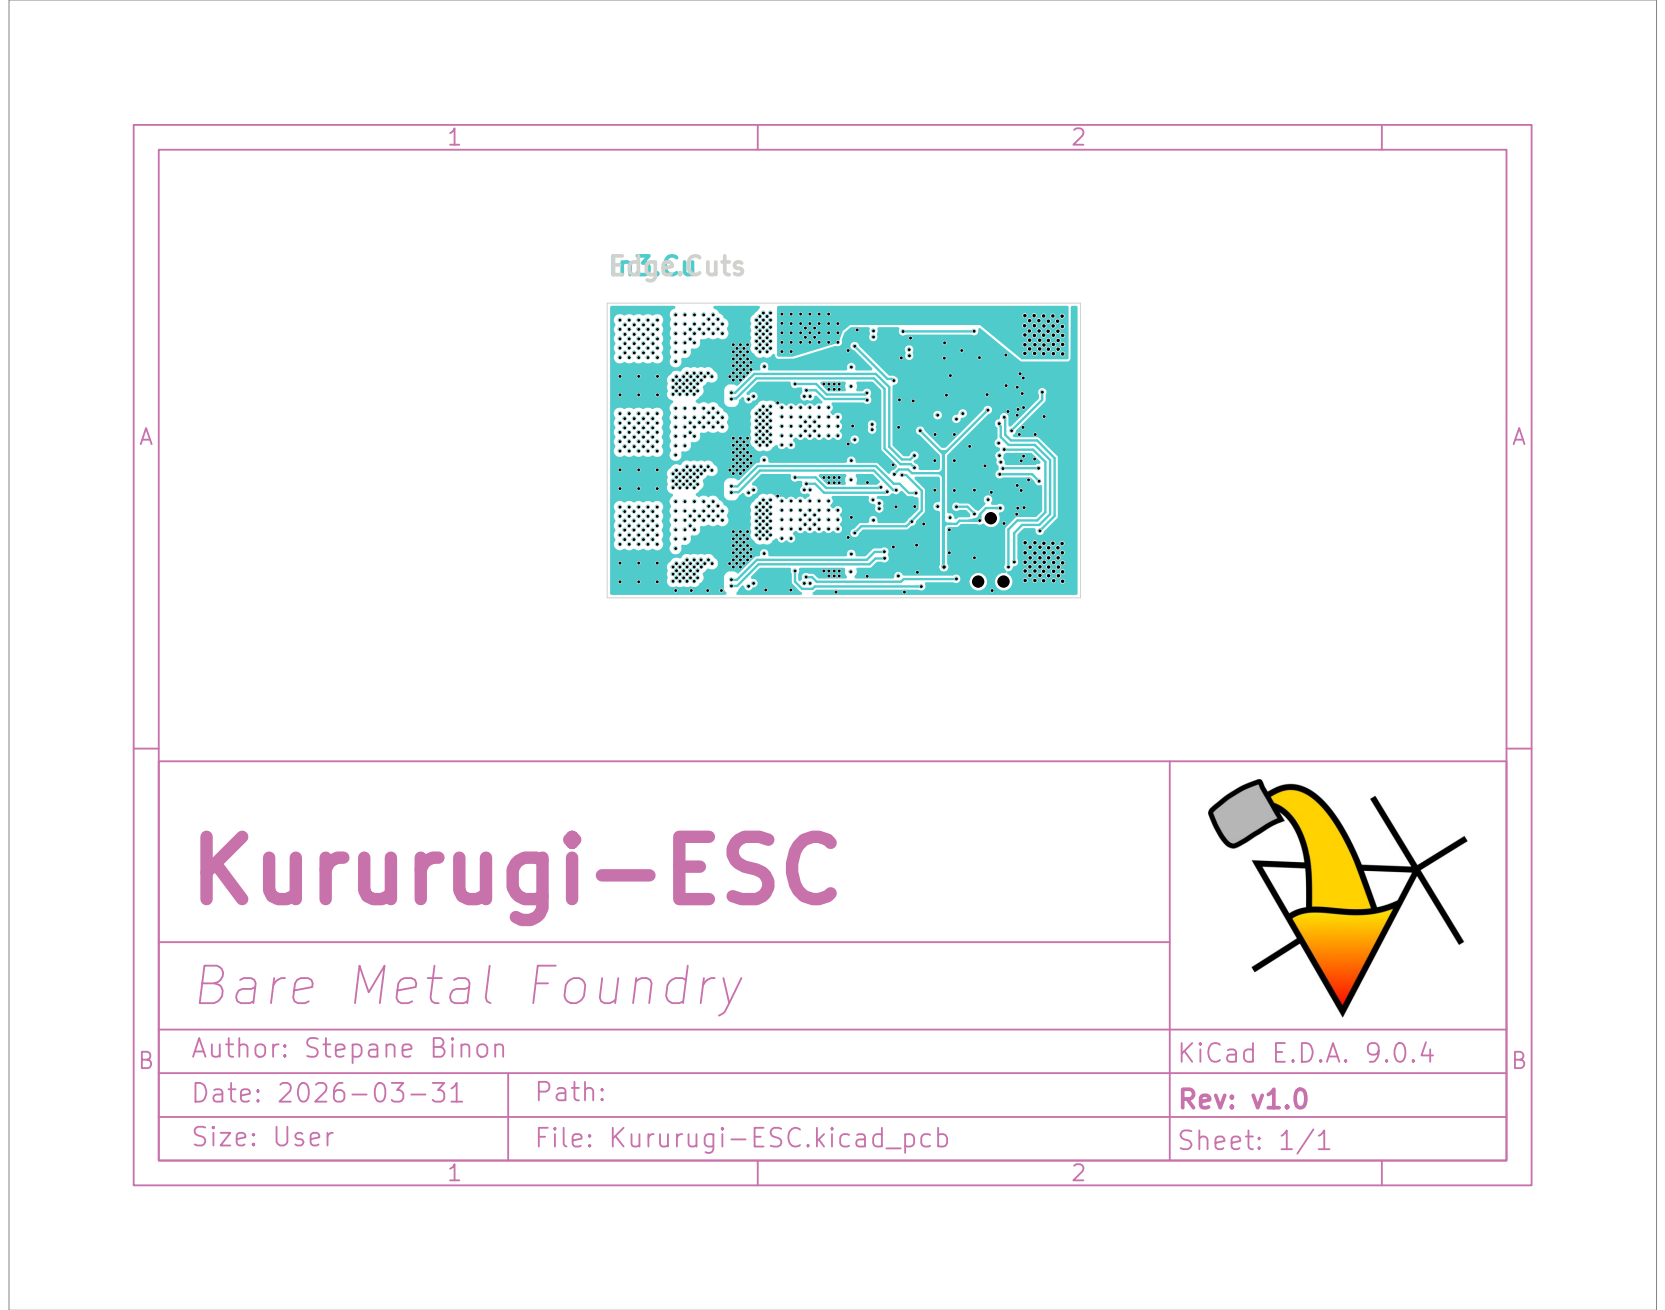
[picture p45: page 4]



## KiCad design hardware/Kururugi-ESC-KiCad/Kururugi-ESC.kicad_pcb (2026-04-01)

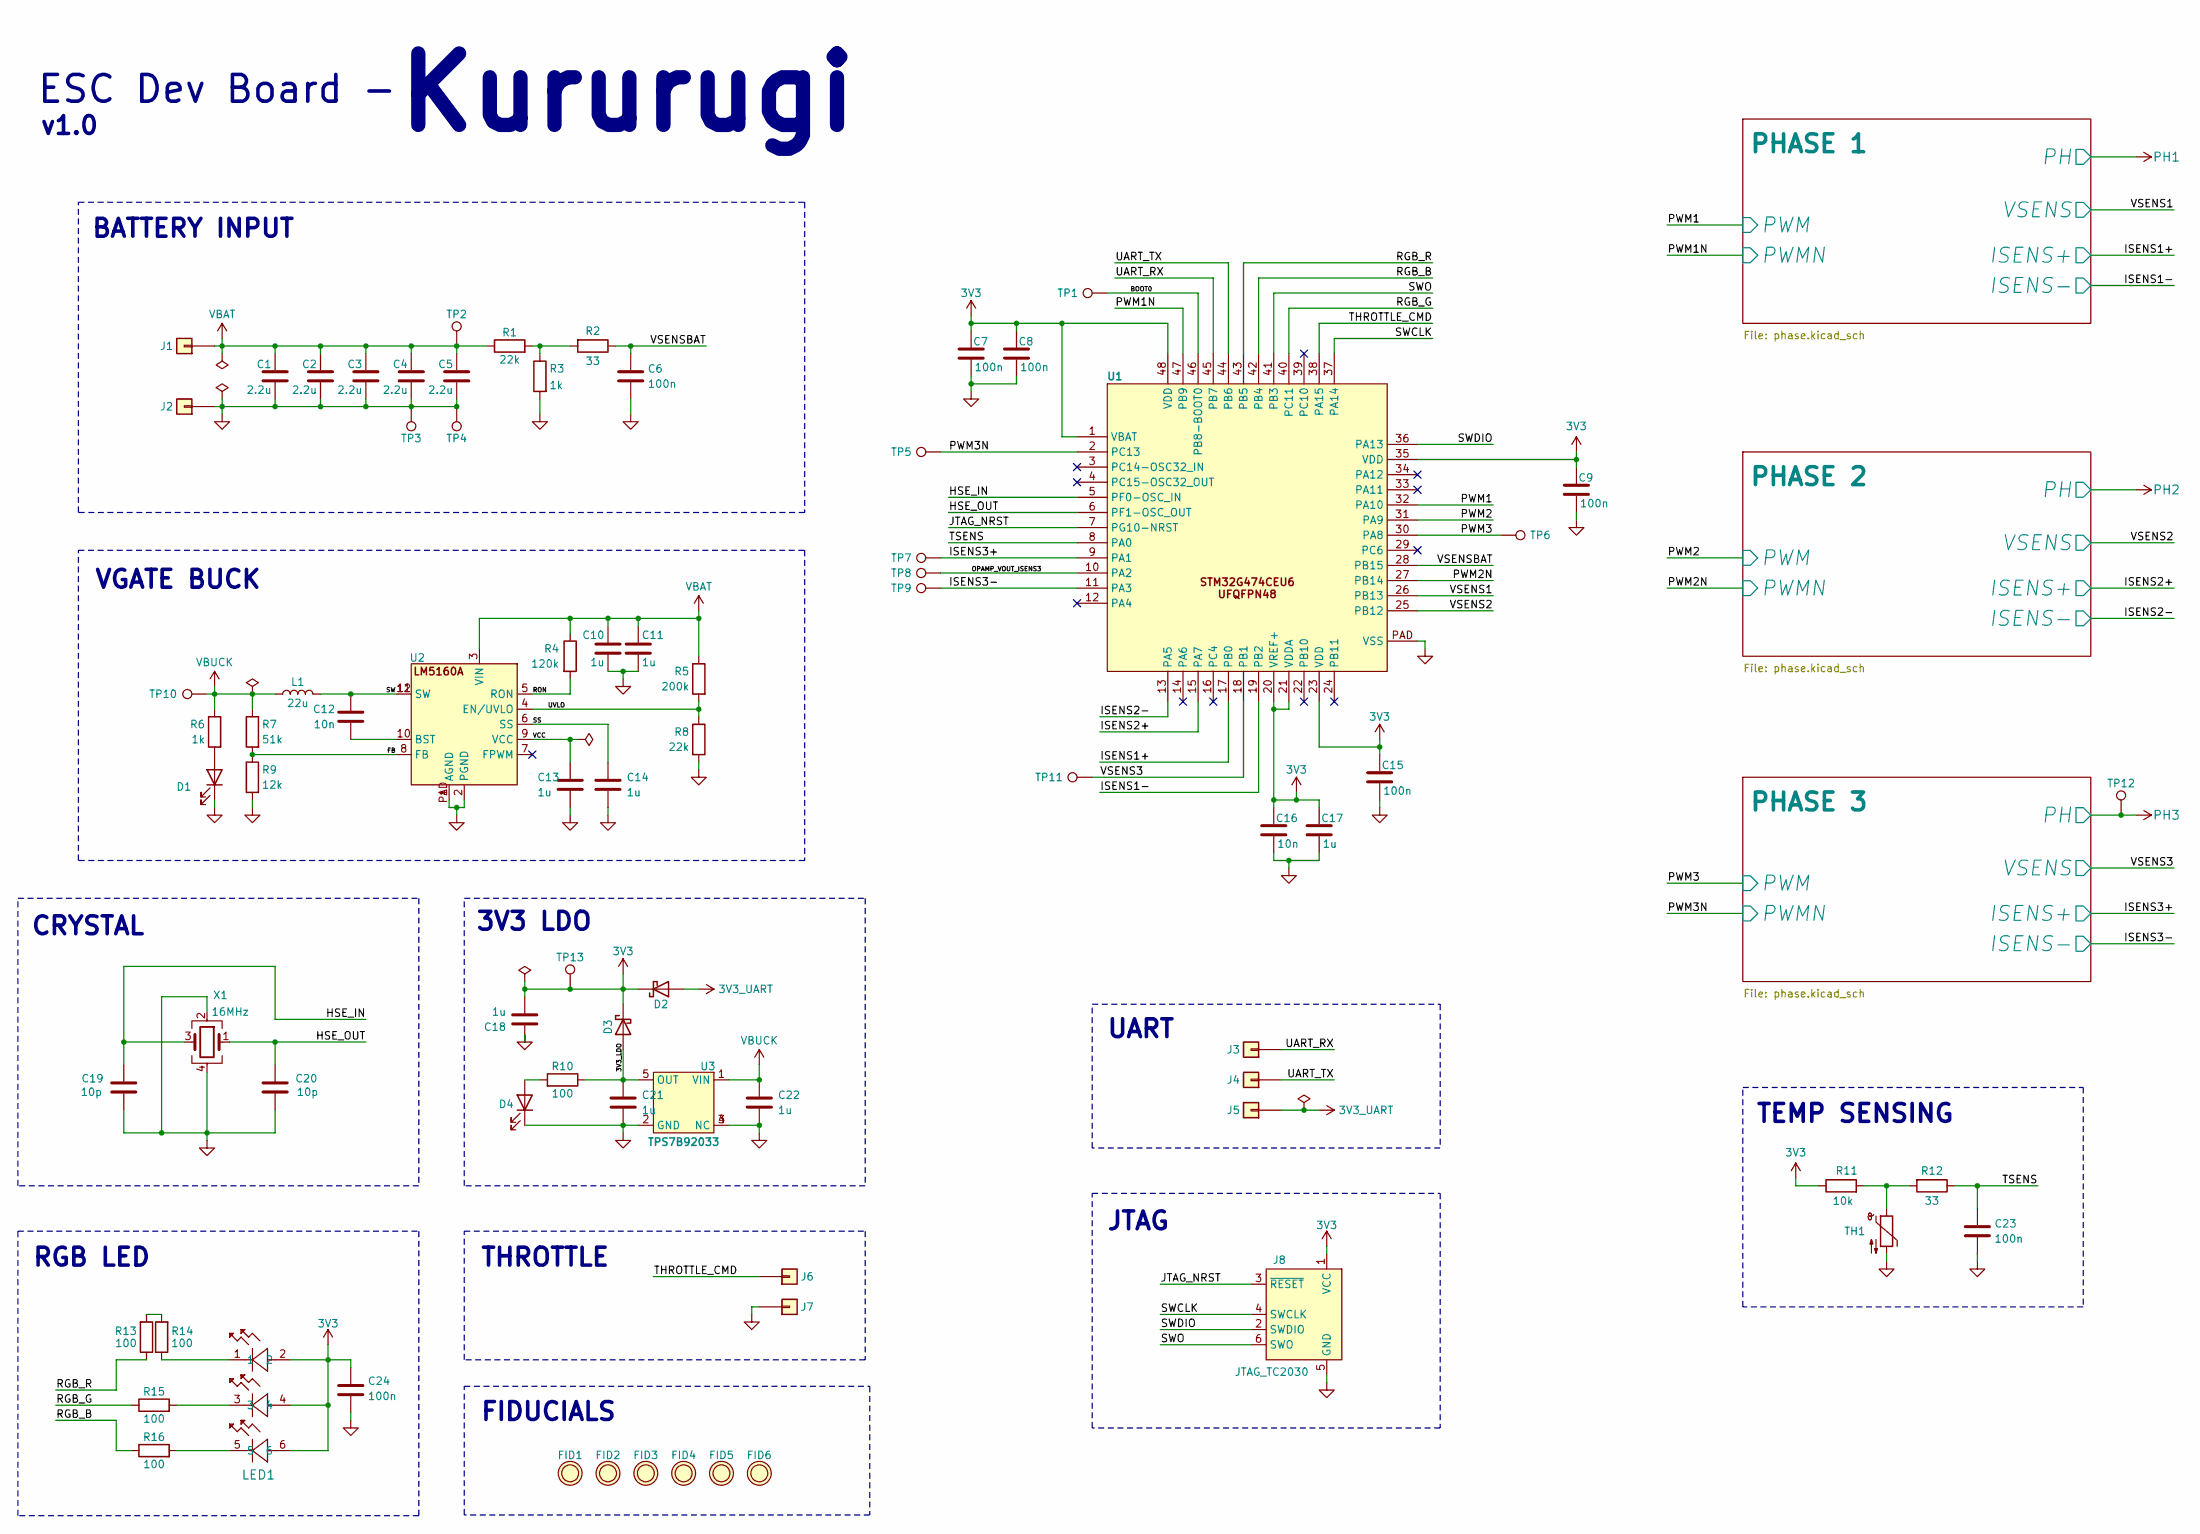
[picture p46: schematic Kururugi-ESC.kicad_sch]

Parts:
C1, C2, C3, C4, C5: 2.2u; C_1206_3216Metric; Manufacturer Part Number CL31B225KBHNNNE; LCSC C50254
C6, C7, C8, C9, C15, C23, C24: 100n; C_0402_1005Metric; Manufacturer Part Number CL05B104KO5NNNC; LCSC C1525
C10, C11, C13, C14, C18, C21, C22: 1u; C_0402_1005Metric; Manufacturer Part Number CL05A105KA5NQNC; LCSC C52923
C12, C16: 10n; C_0402_1005Metric; Manufacturer Part Number CL05B103KB5NNNC; LCSC C15195
C17: 1u; C_0603_1608Metric; Manufacturer Part Number CL10A105KB8NNNC; LCSC C15849
C19, C20: 10p; C_0402_1005Metric; Manufacturer Part Number CL05C100JB5NNNC; LCSC C32949
D1, D4: KT-0603W; LED_0603_1608Metric; Manufacturer Part Number KT-0603W; LCSC C2290
D2, D3: RB161QS-40T18R; Rohm_SMD1006; Manufacturer Part Number RB161QS-40T18R; LCSC C2837790
FID1, FID2, FID3, FID4, FID5, FID6: Fiducial_0.5mm_Mask1mm
J1, J2: Conn_01x01; Phase4x4
J3, J4, J5, J6, J7: Conn_01x01; TestPoint_Pad_2.0x2.0mm
J8: JTAG_TC2030; Tag-Connect_TC2030-IDC-NL_2x03_P1.27mm_Vertical
L1: 22u; LVS404018-220M-N; Manufacturer Part Number LVS404018-220M-N; LCSC C116614
LED1: 19-337C/RSBHGHC-A88/4T; SMD-B_19-337C_EVE; Manufacturer Part Number 19-337C/RSBHGHC-A88/4T; LCSC C3019536
R1, R8: 22k; R_0402_1005Metric; Manufacturer Part Number 0402WGF2202TCE; LCSC C25768
R2, R12: 33; R_0402_1005Metric; Manufacturer Part Number 0402WGF330JTCE; LCSC C25105
R3, R6: 1k; R_0402_1005Metric; Manufacturer Part Number 0402WGF1001TCE; LCSC C11702
R4: 120k; R_0603_1608Metric; Manufacturer Part Number 0603WAF1203T5E; LCSC C25808
R5: 200k; R_0402_1005Metric; Manufacturer Part Number 0402WGF2003TCE; LCSC C25764
R7: 51k; R_0402_1005Metric; Manufacturer Part Number 0402WGF5102TCE; LCSC C25794
R9: 12k; R_0402_1005Metric; Manufacturer Part Number 0402WGF1202TCE; LCSC C25752
R10, R13, R14, R15, R16: 100; C_0402_1005Metric; Manufacturer Part Number 0402WGF1000TCE; LCSC C25076
R11: 10k; R_0402_1005Metric; Manufacturer Part Number 0402WGF1002TCE; LCSC C25744
TH1: Thermistor_NTC; R_0402_1005Metric; Manufacturer Part Number NTCG103JF103FT1; LCSC C209959
TP1, TP2, TP3, TP4, TP5, TP6, TP7, TP8, TP9, TP10, TP11, TP12, TP13: TestPoint; TestPoint_Pad_D1.0mm
U1: STM32G474CEU6; Manufacturer Part Number STM32G474CEU6; LCSC C1235412
U2: LM5160A; LM5160ADNTR; Manufacturer Part Number LM5160ADNTR; LCSC C473375
U3: TPS7B92033; TI-SOT-23 (5p); Manufacturer Part Number TPS7B92033DBVR; LCSC C32353919
X1: 16MHz; YXC-X322516MLB4SI; Manufacturer Part Number X322516MLB4SI; LCSC C13738

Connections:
3V3: C7.1, C8.1, C9.1, C15.1, C16.1, C17.1, C18.2, C24.1, D2.1 (K), D3.1 (K), J8.1 (VCC), LED1.2, LED1.4, LED1.6, R11.1, TP13.1, U1.1 (VBAT), U1.20 (VREF+), U1.21 (VDDA), U1.23 (VDD), U1.35 (VDD), U1.48 (VDD)
3V3_UART: D2.2 (A), J5.1
/3V3_LDO: C21.1, D3.2 (A), R10.1, U3.5 (OUT)
/BOOT0: TP1.1, U1.46 (PB8-BOOT0)
/FB: R7.2, R9.1, U2.8 (FB)
/HSE_IN: C19.1, U1.5 (PF0-OSC_IN), X1.3
/HSE_OUT: C20.1, U1.6 (PF1-OSC_OUT), X1.1
/ISENS1+: U1.17 (PB0); also elsewhere on the board
/ISENS1-: U1.19 (PB2); also elsewhere on the board
/ISENS2+: U1.15 (PA7); also elsewhere on the board
/ISENS2-: U1.13 (PA5); also elsewhere on the board
/ISENS3+: TP7.1, U1.9 (PA1); also elsewhere on the board
/ISENS3-: TP9.1, U1.11 (PA3); also elsewhere on the board
/JTAG_NRST: J8.3 (~RESET), U1.7 (PG10-NRST)
/OPAMP_VOUT_ISENS3: TP8.1, U1.10 (PA2)
/PWM1: U1.32 (PA10); also elsewhere on the board
/PWM1N: U1.47 (PB9); also elsewhere on the board
/PWM2: U1.31 (PA9); also elsewhere on the board
/PWM2N: U1.27 (PB14); also elsewhere on the board
/PWM3: TP6.1, U1.30 (PA8); also elsewhere on the board
/PWM3N: TP5.1, U1.2 (PC13); also elsewhere on the board
/RGB_B: R16.1, U1.42 (PB4)
/RGB_G: R15.1, U1.40 (PC11)
/RGB_R: R13.1, U1.43 (PB5)
/RON: R4.2, U2.5 (RON)
/SS: C14.1, U2.6 (SS)
/SW: C12.1, L1.1, U2.11 (SW), U2.12 (SW)
/SWCLK: J8.4 (SWCLK), U1.37 (PA14)
/SWDIO: J8.2 (SWDIO), U1.36 (PA13)
/SWO: J8.6 (SWO), U1.41 (PB3)
/THROTTLE_CMD: J6.1, U1.38 (PA15)
/TSENS: C23.1, R12.1, U1.8 (PA0)
/UART_RX: J3.1, U1.45 (PB7)
/UART_TX: J4.1, U1.44 (PB6)
/UVLO: R5.2, R8.1, U2.4 (EN/UVLO)
/VCC: C13.1, U2.9 (VCC)
/VSENS1: U1.26 (PB13); also elsewhere on the board
/VSENS2: U1.25 (PB12); also elsewhere on the board
/VSENS3: TP11.1, U1.18 (PB1); also elsewhere on the board
/VSENSBAT: C6.1, R2.1, U1.28 (PB15)
GND: C1.2, C2.2, C3.2, C4.2, C5.2, C6.2, C7.2, C8.2, C9.2, C10.2, C11.2, C13.2, C14.2, C15.2, C16.2, C17.2, C18.1, C19.2, C20.2, C21.2, C22.2, C23.2, C24.2, D1.1 (K), D4.1 (K), J2.1, J7.1, J8.5 (GND), R3.2, R8.2, R9.2, TH1.2, TP3.1, TP4.1, U1.PAD (VSS), U2.1 (AGND), U2.2 (PGND), U2.PAD (AGND), U3.2 (GND), U3.3 (NC), U3.4 (NC), X1.2, X1.4; also elsewhere on the board
unnamed: D1.2 (A), R6.2
unnamed: D4.2 (A), R10.2
unnamed: LED1.1, R14.1
unnamed: LED1.3, R15.2
unnamed: LED1.5, R16.2
unnamed: R1.2, R2.2, R3.1
unnamed: R11.2, R12.2, TH1.1
unnamed: R13.2, R14.2
unnamed: C12.2, U2.10 (BST)
PH3: TP12.1; also elsewhere on the board
VBAT: C1.1, C2.1, C3.1, C4.1, C5.1, C10.1, C11.1, J1.1, R1.1, R4.1, R5.1, TP2.1, U2.3 (VIN); also elsewhere on the board
VBUCK: C22.1, L1.2, R6.1, R7.1, TP10.1, U3.1 (VIN); also elsewhere on the board

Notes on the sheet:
Kururugi
UART
JTAG
THROTTLE
RGB LED
CRYSTAL
BATTERY INPUT
VGATE BUCK
TEMP SENSING
ESC Dev Board -
3V3 LDO
${REVISION}
FIDUCIALS

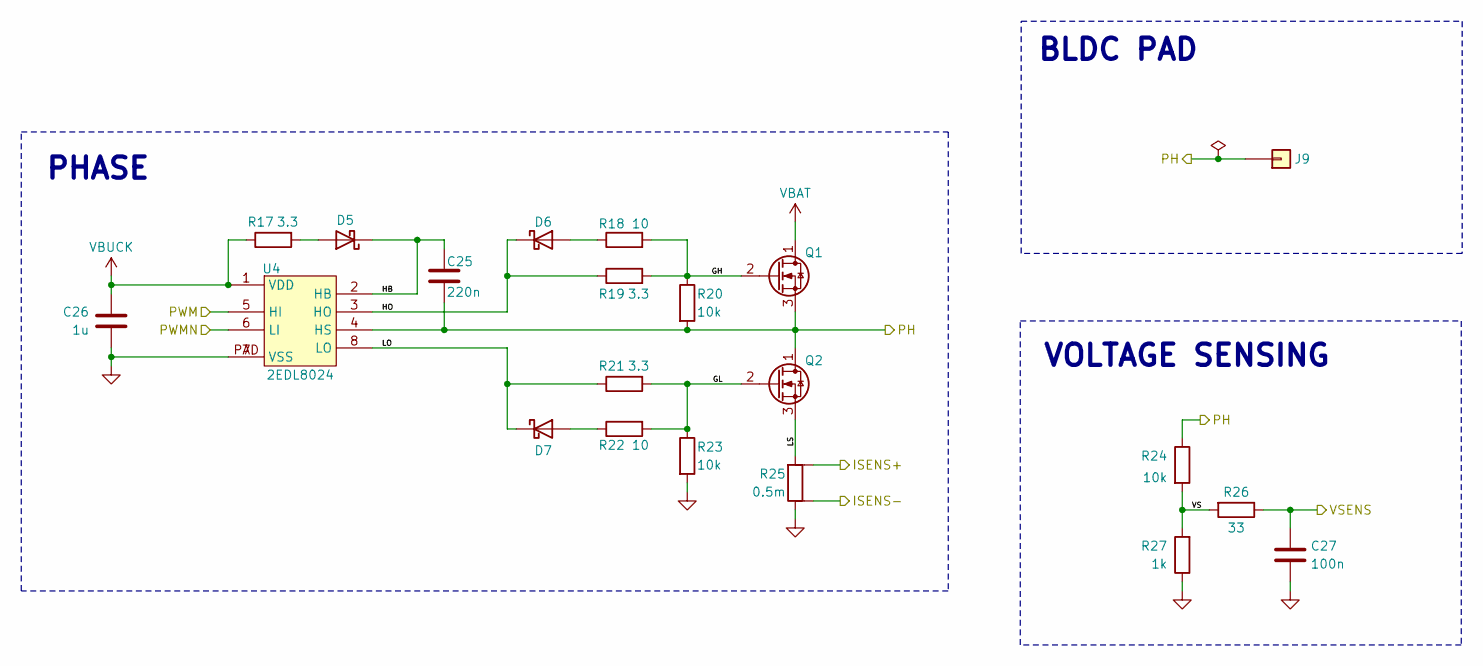
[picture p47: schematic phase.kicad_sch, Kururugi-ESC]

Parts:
C25: 220n; C_0402_1005Metric; Manufacturer Part Number CL05B224KO5NNNC; LCSC C16772
C26: 1u; C_0603_1608Metric; Manufacturer Part Number CL10A105KB8NNNC; LCSC C15849
C27: 100n; C_0402_1005Metric; Manufacturer Part Number CL05B104KO5NNNC; LCSC C1525
D5, D6, D7: RB161QS-40T18R; Rohm_SMD1006; Manufacturer Part Number RB161QS-40T18R; LCSC C2837790
J9: Conn_01x01; Phase4x4
Q1, Q2: CSD18540Q5B; Manufacturer Part Number CSD18540Q5B; LCSC C86513
R17, R19, R21: 3.3; R_0402_1005Metric; Manufacturer Part Number 0402WGJ033JTCE; LCSC C25165
R18, R22: 10; R_0402_1005Metric; Manufacturer Part Number 0402WGF100JTCE; LCSC C25077
R20, R23, R24: 10k; R_0402_1005Metric; Manufacturer Part Number 0402WGF1002TCE; LCSC C25744
R25: 0.5m; HoBB1216-5W-0.5mR-1; Manufacturer Part Number HoBB1216-5W-0.5mR-1%; LCSC C17701556
R26: 33; R_0402_1005Metric; Manufacturer Part Number 0402WGF330JTCE; LCSC C25105
R27: 1k; R_0402_1005Metric; Manufacturer Part Number 0402WGF1001TCE; LCSC C11702
U4: 2EDL8024; Manufacturer Part Number 2EDL8024G; LCSC C3655215

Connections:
/ISENS1+: R25.1; also elsewhere on the board
/ISENS1-: R25.4; also elsewhere on the board
/PHASE 1/GH: Q1.2 (G), R18.2, R19.2, R20.1
/PHASE 1/GL: Q2.2 (G), R21.2, R22.2, R23.1
/PHASE 1/HB: C25.1, D5.1 (K), U4.2 (HB)
/PHASE 1/HO: D6.1 (K), R19.1, U4.3 (HO)
/PHASE 1/LO: D7.1 (K), R21.1, U4.8 (LO)
/PHASE 1/LS: Q2.3 (S), R25.2
/PHASE 1/VS: R24.2, R26.2, R27.2
/PWM1: U4.5 (HI); also elsewhere on the board
/PWM1N: U4.6 (LI); also elsewhere on the board
/VSENS1: C27.1, R26.1; also elsewhere on the board
GND: C26.2, C27.2, R23.2, R25.3, R27.1, U4.7 (VSS), U4.PAD (VSS); also elsewhere on the board
unnamed: D5.2 (A), R17.2
unnamed: D6.2 (A), R18.1
unnamed: D7.2 (A), R22.1
PH1: C25.2, J9.1, Q1.3 (S), Q2.1 (D), R20.2, R24.1, U4.4 (HS)
VBAT: Q1.1 (D); also elsewhere on the board
VBUCK: C26.1, R17.1, U4.1 (VDD); also elsewhere on the board

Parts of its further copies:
C28, C31: 220n; C_0402_1005Metric; Manufacturer Part Number CL05B224KO5NNNC; LCSC C16772
C29, C32: 1u; C_0603_1608Metric; Manufacturer Part Number CL10A105KB8NNNC; LCSC C15849
C30, C33: 100n; C_0402_1005Metric; Manufacturer Part Number CL05B104KO5NNNC; LCSC C1525
D8, D9, D10, D11, D12, D13: RB161QS-40T18R; Rohm_SMD1006; Manufacturer Part Number RB161QS-40T18R; LCSC C2837790
J10, J11: Conn_01x01; Phase4x4
Q3, Q4, Q5, Q6: CSD18540Q5B; Manufacturer Part Number CSD18540Q5B; LCSC C86513
R28, R30, R32, R39, R41, R43: 3.3; R_0402_1005Metric; Manufacturer Part Number 0402WGJ033JTCE; LCSC C25165
R29, R33, R40, R44: 10; R_0402_1005Metric; Manufacturer Part Number 0402WGF100JTCE; LCSC C25077
R31, R34, R35, R42, R45, R46: 10k; R_0402_1005Metric; Manufacturer Part Number 0402WGF1002TCE; LCSC C25744
R36, R47: 0.5m; HoBB1216-5W-0.5mR-1; Manufacturer Part Number HoBB1216-5W-0.5mR-1%; LCSC C17701556
R37, R48: 33; R_0402_1005Metric; Manufacturer Part Number 0402WGF330JTCE; LCSC C25105
R38, R49: 1k; R_0402_1005Metric; Manufacturer Part Number 0402WGF1001TCE; LCSC C11702
U5, U6: 2EDL8024; Manufacturer Part Number 2EDL8024G; LCSC C3655215

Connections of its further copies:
/ISENS2+: R36.1; also elsewhere on the board
/ISENS2-: R36.4; also elsewhere on the board
/ISENS3+: R47.1; also elsewhere on the board
/ISENS3-: R47.4; also elsewhere on the board
/PHASE 2/GH: Q3.2 (G), R29.2, R30.2, R31.1
/PHASE 2/GL: Q4.2 (G), R32.2, R33.2, R34.1
/PHASE 2/HB: C28.1, D8.1 (K), U5.2 (HB)
/PHASE 2/HO: D9.1 (K), R30.1, U5.3 (HO)
/PHASE 2/LO: D10.1 (K), R32.1, U5.8 (LO)
/PHASE 2/LS: Q4.3 (S), R36.2
/PHASE 2/VS: R35.2, R37.2, R38.2
/PHASE 3/GH: Q5.2 (G), R40.2, R41.2, R42.1
/PHASE 3/GL: Q6.2 (G), R43.2, R44.2, R45.1
/PHASE 3/HB: C31.1, D11.1 (K), U6.2 (HB)
/PHASE 3/HO: D12.1 (K), R41.1, U6.3 (HO)
/PHASE 3/LO: D13.1 (K), R43.1, U6.8 (LO)
/PHASE 3/LS: Q6.3 (S), R47.2
/PHASE 3/VS: R46.2, R48.2, R49.2
/PWM2: U5.5 (HI); also elsewhere on the board
/PWM2N: U5.6 (LI); also elsewhere on the board
/PWM3: U6.5 (HI); also elsewhere on the board
/PWM3N: U6.6 (LI); also elsewhere on the board
/VSENS2: C30.1, R37.1; also elsewhere on the board
/VSENS3: C33.1, R48.1; also elsewhere on the board
GND: C29.2, C30.2, C32.2, C33.2, R34.2, R36.3, R38.1, R45.2, R47.3, R49.1, U5.7 (VSS), U5.PAD (VSS), U6.7 (VSS), U6.PAD (VSS); also elsewhere on the board
unnamed: D8.2 (A), R28.2
unnamed: D9.2 (A), R29.1
unnamed: D10.2 (A), R33.1
unnamed: D11.2 (A), R39.2
unnamed: D12.2 (A), R40.1
unnamed: D13.2 (A), R44.1
PH2: C28.2, J10.1, Q3.3 (S), Q4.1 (D), R31.2, R35.1, U5.4 (HS)
PH3: C31.2, J11.1, Q5.3 (S), Q6.1 (D), R42.2, R46.1, U6.4 (HS); also elsewhere on the board
VBAT: Q3.1 (D), Q5.1 (D); also elsewhere on the board
VBUCK: C29.1, C32.1, R28.1, R39.1, U5.1 (VDD), U6.1 (VDD); also elsewhere on the board

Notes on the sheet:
PHASE
BLDC PAD
VOLTAGE SENSING

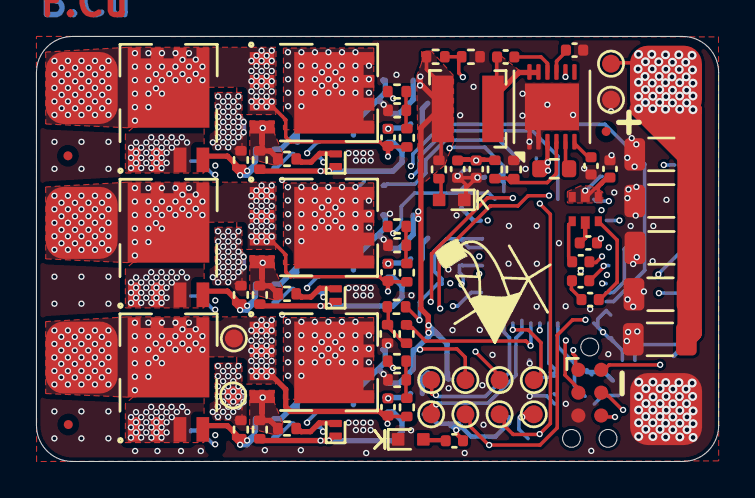
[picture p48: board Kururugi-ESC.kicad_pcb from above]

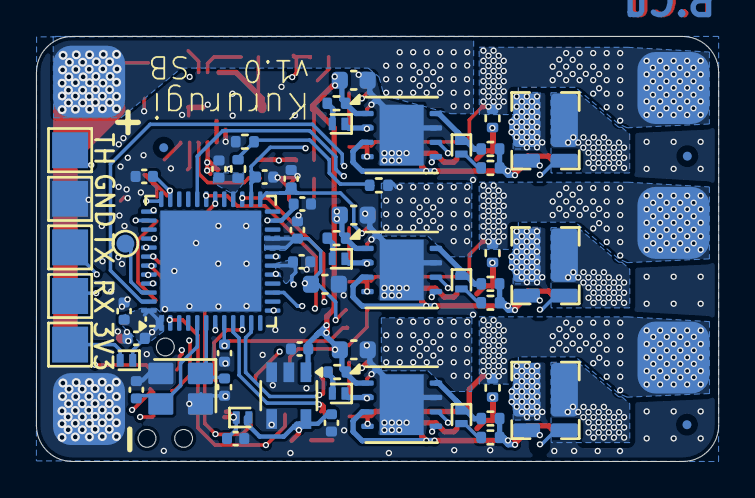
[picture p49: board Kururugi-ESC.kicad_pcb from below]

Board: 6 copper layers, 37.9 x 23.6 mm, 141 parts (60 on the bottom side), 85 nets.

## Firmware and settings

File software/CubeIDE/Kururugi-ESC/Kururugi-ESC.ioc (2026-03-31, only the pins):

Mcu.UserName=STM32G484CEUx
PA0.GPIO_Label=TSENS
PA0.Signal=ADC2_IN1
PA1.GPIO_Label=AMP1VINP_ISENS3+
PA1.Signal=OPAMP1_VINP
PA10.GPIO_Label=TIM1CH3_PH1
PA10.Signal=S_TIM1_CH3
PA13.GPIO_Label=SWDIO
PA13.Signal=SYS_JTMS-SWDIO
PA14.GPIO_Label=SWCLK
PA14.Signal=SYS_JTCK-SWCLK
PA15.GPIO_Label=TIM2CH1_TH
PA15.Signal=S_TIM2_CH1
PA2.GPIO_Label=AMP1VOUT_ISENS3
PA2.Signal=OPAMP1_VOUT
PA3.GPIO_Label=AMP1VINM_ISENS3-
PA3.Signal=OPAMP1_VINM0
PA5.GPIO_Label=AMP2VINM_ISENS2-
PA5.Signal=OPAMP2_VINM0
PA7.GPIO_Label=AMP2VINP_ISENS2+
PA7.Signal=OPAMP2_VINP
PA8.GPIO_Label=TIM1CH1_PH3
PA8.Signal=S_TIM1_CH1
PA9.GPIO_Label=TIM1CH2_PH2
PA9.Signal=S_TIM1_CH2
PB0.GPIO_Label=AMP3VINP_ISENS1+
PB0.Signal=OPAMP3_VINP
PB1.GPIO_Label=ADC1IN12_VSENS3
PB1.Signal=ADC1_IN12
PB12.GPIO_Label=ADC4IN3_VSENS2
PB12.Signal=ADC4_IN3
PB13.GPIO_Label=ADC3IN5_VSENS1
PB13.Signal=ADC3_IN5
PB14.GPIO_Label=TIM1CH2N_PH2N
PB14.Signal=TIM1_CH2N
PB15.GPIO_Label=ADC4IN5_VBATSENS
PB15.Signal=ADC4_IN5
PB2.GPIO_Label=AMP3VINM_ISENS1-
PB2.Signal=OPAMP3_VINM0
PB3.GPIO_Label=SWO
PB3.Signal=SYS_JTDO-SWO
PB4.GPIO_Label=RGB_B
PB4.Signal=GPIO_Output
PB5.GPIO_Label=RGB_R
PB5.Signal=GPIO_Output
PB6.GPIO_Label=UART_TX
PB6.Signal=USART1_TX
PB7.GPIO_Label=UART_RX
PB7.Signal=USART1_RX
PB9.GPIO_Label=TIM1CH3N_PH1N
PB9.Signal=TIM1_CH3N
PC11.GPIO_Label=RGB_G
PC11.Signal=GPIO_Output
PC13.GPIO_Label=TIM1CH1N_PH3N
PC13.Signal=TIM1_CH1N
PF0-OSC_IN.GPIO_Label=HSE_IN
PF0-OSC_IN.Signal=RCC_OSC_IN
PF1-OSC_OUT.GPIO_Label=HSE_OUT
PF1-OSC_OUT.Signal=RCC_OSC_OUT

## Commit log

2026-02-03 Additionnal documentation
    [Kururugi-ESC-calculs.xlsx, Naming.xlsx]
2026-02-03 Kicad Update
    [ESC_v1.0.kicad_sch]
2026-02-05 New docs
    [Kururugi-ESC-calculs.xlsx]
2026-02-08 Update on doc and kicad
    [ESC_v1.0.kicad_sch, Kururugi-ESC-calculs.xlsx]
2026-02-08 Update gate driver
    [ESC_v1.0.kicad_sch, Kururugi-ESC-calculs.xlsx]
2026-02-10 Update doc and kicad
    [ESC_v1.0.kicad_sch, Kururugi-ESC-calculs.xlsx]
2026-02-11 Update kicad and docs
    [ESC_v1.0.kicad_sch, Kururugi-ESC-calculs.xlsx]
2026-02-12 Update kicad and doc
    [ESC_v1.0.kicad_pcb, Kururugi-ESC-calculs.xlsx]
2026-02-15 Kicad and esc choice review
    [ESC_v1.0.kicad_sch, Kururugi-ESC-calculs.xlsx]
2026-02-15 Excel review
    [Kururugi-ESC-calculs.xlsx]
2026-02-19 Excel calculus update
    [Kururugi-ESC-calculs.xlsx]
2026-02-21 Final excel version
    [Kururugi-ESC-calculs.xlsx]
2026-02-21 Update kicad
    [ESC_v1.0.kicad_sch, Kururugi-ESC-calculs.xlsx]
2026-03-01 V1 schematic
    [ESC_v1.0.kicad_pcb, ESC_v1.0.kicad_sch, example.kicad_pcb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]
2026-03-01 First PCB
    [ESC_v1.0.kicad_pcb, ESC_v1.0.kicad_sch, Kururugi-ESC-calculs.xlsx]
2026-03-25 Major board update
    [19-337C_RSBHGHC-A88_4T.STEP, DNT0012B.stp, ESC_v1.0.kicad_pcb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]
2026-03-28 Major Kicad Update
    [ESC_v1.0.kicad_pcb, ESC_v1.0.kicad_sch, phase.kicad_sch]
2026-03-29 Fix kicad
    [ESC_v1.0.kicad_pcb, ESC_v1.0.kicad_sch, phase.kicad_sch]
2026-03-30 Update documentation
    [ESC_v1.0.kicad_pcb, ESC_v1.0.kicad_sch, Kururugi-ESC-calculs.xlsx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]
2026-03-30 Documentation review
    [ESC_v1.0.kicad_pcb, ESC_v1.0.kicad_sch, Kururugi-ESC-sizing.xlsx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]
2026-03-31 Doc Update + Added CubeIDE
    [Kururugi-ESC-sizing.xlsx, Kururugi-ESC.kicad_pcb, Kururugi-ESC.kicad_sch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]
2026-03-31 Kicad minor corrections
    [Kururugi-ESC.kicad_pcb, Kururugi-ESC.kicad_sch, extern.kicad_sch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]
2026-03-31 G484 -> G474
    [Kururugi-ESC.kicad_pcb]
2026-04-01 Path change for KiCad project
    [Kururugi-ESC.kicad_pcb, Kururugi-ESC.kicad_sch, Kururugi-ESC.step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]
2026-04-01 Licensing on hardware
    [Kururugi-ESC.step]
2026-04-01 Remove old component library
    [Component-Library.xlsx]
2026-04-01 Name and README update
    [Kururugi-ESC.kicad_pcb]
2026-04-01 PCB view improvments
    [Kururugi-ESC.kicad_pcb, Kururugi-ESC.kicad_sch]
2026-04-01 PCB Improvments
    [Kururugi-ESC.kicad_pcb]
2026-04-08 Excel corrections & AN5397 & imgs
    [Kururugi-ESC-sizing.xlsx]
2026-04-08 Add ESC logic draft doc
